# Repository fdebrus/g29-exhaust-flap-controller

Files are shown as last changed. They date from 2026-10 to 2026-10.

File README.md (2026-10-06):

# G29 Exhaust Flap Controller

Open-source controller for the exhaust flap of the **BMW Z4 G29 M40i**: open the flap on demand
(even in Comfort mode) while keeping **full factory behaviour** the rest of the time.

Commercial kits exist, but the cheap ones replace the factory control entirely (their "AUTO" mode
does not hand control back to the car). This project fixes that with a fail-safe relay design.

## How it works

```
                       +------------------+
Engine computer (DME) -| NC              |
                       |   DPDT relay    COM|--- Exhaust flap actuator (signal wire)
ESP32-C3 PWM driver ---| NO              |
                       +------------------+
```

- **AUTO** (default, relay released): the car drives the flap exactly as from the factory.
- **ON / OFF**: the ESP32-C3 energizes the relay and sends its own PWM signal (flap open / closed).
- **Fail-safe**: if the board loses power, resets or crashes, the relay drops and the car is back in control.
- Only the **signal wire** is cut. The actuator's +12 V and ground stay on the original harness.
  The board takes its own power from a fused source in the trunk, not from the actuator wires.
- The relay's second pole connects a **dummy load** to the DME while the ESP32-C3 is in control,
  to try to avoid an open-circuit fault code.

Controls: the original 433 MHz key fob (ON / AUTO / OFF) and the kit's dashboard button, whose
cabin box also transmits on 433 MHz. Nothing is wired from the dashboard to the board.

## Hardware

Board **v3**: Seeed XIAO ESP32-C3 on socket strips, **on-board 433 MHz receiver** (JSMSEMI
SYN480R + 13.52127 MHz crystal, wire antenna pad), SMT passives (0603/0805, SMA, SOD-123,
SOT-23, DPAK), Omron G5V-2 DPDT relay, two 2-pin screw terminals. **58 x 40 mm**, 2 layers,
29 placed parts, designed for JLCPCB assembly (`hardware/v3-xiao-esp32c3/jlcpcb/`). No RXB6
module any more.

Earlier boards are in the git history only: v2 (same circuit with through-hole parts, an RXB6
module and a wired dashboard input, 60 x 46 mm) before the `v2-removed` tag, v1 (ESP32-DevKitC)
before the `v1-removed` tag.

## Project status

- [x] Teardown and analysis of the commercial kit ([docs/findings.md](docs/findings.md))
- [x] Firmware (AUTO / ON / OFF over 433 MHz: fob + dashboard button, fail-safe start)
- [x] PCB v3 (XIAO ESP32-C3, on-board SYN480R receiver, SMT, 58 x 40 mm, 3 mounting holes, DRC clean)
- [x] 3D-printed enclosure (OpenSCAD, 62.8 x 44.8 x 26 mm, not yet test-printed)
- [ ] Receiver sensitivity check against an RXB6 (first board)
- [x] Harness survey on the car: tap point and wire identification ([docs/harness.md](docs/harness.md))
- [ ] **Bench measurement of the kit's output signal** ([docs/measurement.md](docs/measurement.md))
- [ ] Measurement on the car (DME signal, actuator input impedance)
- [ ] Set PWM frequency / duty cycles in the firmware
- [ ] Verify XIAO footprint (1:1 print) and order the assembled PCB
- [ ] Assembly, bench test, installation ([docs/installation.md](docs/installation.md))
- [ ] Check fault memory after a few drives

## Repository layout

| Path | Content |
| --- | --- |
| `firmware/g29_exhaust_flap_xiao/` | Firmware (Seeed XIAO ESP32-C3) |
| `hardware/v3-xiao-esp32c3/` | KiCad board, Gerbers, previews, DRC report, JLCPCB BOM + CPL, 3D-printed enclosure |
| `tools/pcb-generator/` | Scripts that regenerate the board (KiCad 7 + freerouting) |
| `docs/` | Findings, harness survey, measurement, installation, shopping list |

## Important values still to confirm

The firmware PWM values are **placeholders** until measured:

| Parameter | Current value | Source |
| --- | --- | --- |
| `PWM_FREQ_HZ` | 100 | guess - **must be measured** |
| `DUTY_OPEN_PCT` | 95 % | BMW F30 measurement, not verified on G29 |
| `DUTY_CLOSED_PCT` | 5 % | BMW F30 measurement, not verified on G29 |

## Disclaimer

Personal project, provided as-is. Modifying the exhaust behaviour may affect road legality
(noise approval), the vehicle inspection, warranty and insurance. The DME may log fault codes while
the controller is in ON/OFF mode. Measure before connecting anything to the car. Use at your own risk.

## License

MIT - see [LICENSE](LICENSE).

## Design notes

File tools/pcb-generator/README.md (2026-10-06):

# PCB generator (v3)

Regenerates `hardware/v3-xiao-esp32c3` from Python, so placement changes are reproducible.

Requirements: KiCad 7 (with the `pcbnew` Python module and standard footprint libraries),
Java 21, [freerouting](https://github.com/freerouting/freerouting) 2.x.

```bash
FREEROUTING_JAR=/path/to/freerouting-2.1.0.jar ./run_all.sh
```

- `build_pcb.py` - footprints, positions, nets, board outline, edge keep-out ring (the netlist lives here)
- `run_all.sh` - design rules (0.3 mm signal / 0.6 mm power, 0.2 mm clearance), Specctra export, autorouting, finishing
- `finish_pcb.py` - imports the routes, adds ground pours and silkscreen, runs DRC

Output: `g29_flap_xiao.kicad_pcb` and `drc.rpt` in this folder. Then:

```bash
kicad-cli pcb export gerbers --layers F.Cu,B.Cu,F.Paste,B.Paste,F.SilkS,B.SilkS,F.Mask,B.Mask,Edge.Cuts -o gerbers/ --no-protel-ext g29_flap_xiao.kicad_pcb
kicad-cli pcb export drill -o gerbers/ --format excellon --excellon-separate-th g29_flap_xiao.kicad_pcb
```

DRC on the current board: 0 errors, 0 warnings (apart from KiCad's "library not configured"
notes, which come from loading footprints by path), 0 unconnected pads.

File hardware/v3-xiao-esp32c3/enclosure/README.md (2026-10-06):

# Enclosure (3D printed)

Parametric OpenSCAD model for board v3 (58 x 40 mm). Outer size **62.8 x 44.8 x 26 mm**
(base 24 mm + lid), inner height 17 mm above the PCB.

## Features
- Board held by **three M2.5 self-tapping screws** (board holes H1-H3) into bosses, plus a
  support ledge along the left edge. Board sits 4 mm above the floor.
- **USB-C opening** in the top wall for the XIAO (flash without opening the box).
- **Two wire openings** in the bottom wall for the J1 and J3 screw terminals.
- **Antenna exit** (3.2 mm) in the top wall right above the ANT pad: the 17 cm wire goes straight
  up from the pad and out. Run it along the harness, away from the relay coil.
- Snap-fit lid with lip and vent slots. Two **fixing tabs** with 4.2 mm holes for cable ties or
  screws in the trunk cavity.

## Printing
PETG or ASA (the trunk gets warm in summer; PLA softens). 0.2 mm layers, 3 perimeters,
20 % infill, no supports: both parts print flat, open side up. Boss hole 2.0 mm for PETG
(`boss_id`), 2.2 mm for harder filaments.

## Files
- `enclosure.scad` - the model; `part = "base" | "lid" | "both"`
- `enclosure_base.stl`, `enclosure_lid.stl`
- `assembly.scad` - board with approximate component bodies inside the base, for the renders
- `render_open.png`, `render_top.png`, `render_exploded.png`

## Regenerating
```bash
openscad -o enclosure_base.stl -D 'part="base"' enclosure.scad
openscad -o enclosure_lid.stl  -D 'part="lid"'  enclosure.scad
xvfb-run openscad -o render_open.png --camera=31,22,14,50,0,200,235 -D show_lid=false assembly.scad
```
All dimensions (wall, clearance, cutout positions, boss size) are parameters at the top of
`enclosure.scad`. Cutout positions are in board coordinates (origin top-left of the PCB).

Not yet test-printed: check the lid snap fit on the first print and adjust `clr` (0.4 mm) if
the board is tight in the cavity.

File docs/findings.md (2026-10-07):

# Findings

Everything we know so far, with how confident we are. "Verified" means seen or measured directly;
"inferred" means deduced, still to be confirmed.

## The car

| Item | Status | Notes |
|---|---|---|
| Z4 G29 M40i has an electrically controlled exhaust flap | Verified | |
| Actuator part number 18308686640, 3-pin connector, driven by the DME | From parts listings | Shared with G20 M340i, G42, G05 X5, F90 M5 and others |
| Signal type is PWM | **Inferred** | See evidence below |
| PWM 5 % = closed, 95 % = open | **Inferred** | Measured on an F30 330i (different actuator), posted on the Pico Technology forum |
| Disconnecting the actuator logs DME fault 138104 (exhaust flap activation, open circuit) | From fault-code listings | Not tested on our car |
| Some commercial modules claim no fault codes | Vendor claim (dAHLer) | Suggests the DME can be kept happy with a load |

## The commercial kit (Chinese, "宝马原厂电机控制器")

The kit has three parts: a replacement light-switch panel with an exhaust button, a cabin box,
a trunk box, and a 3-button key fob (ON / AUTO / OFF). Seller confirmed in writing that it
**replaces** the factory cable: its AUTO button does **not** give control back to the car.

### Key fob
- Resonator marked **R433** -> transmits on **433.92 MHz** (EU-permitted band).

### Cabin box (connected to the dashboard button)
- Blue carrier board with **two plug-in RF modules**, each with its own antenna and an unmarked 8-pin chip.
- Crystals **9.81563 MHz** and **13.52127 MHz**. These match the SYN5xx receiver family values for
  **315 MHz** and **433.92 MHz** respectively.
- Central microcontroller, markings removed.
- Seller's answer "433-315" confirms the two bands.
- Note: 315 MHz is not a permitted short-range band in the EU.

### Trunk box ("HJS-3线电机驱动板-A-V1.1-211118" = "HJS 3-wire motor driver board, A, V1.1, 2021-11-18")
- **U3 marked "531R"** -> likely **SYN531R** ASK receiver; crystal **13.52127 MHz** -> receives on **433.92 MHz**.
- **U1**: 28-pin microcontroller, markings removed. Unpopulated headers P1/P2/P3 (programming/debug).
- **U2**: 78L05 regulator. **D1/D4/D5**: SS14 Schottky. **R1 ("α 075")**: probably a 0.75 A resettable fuse.
- **Output stage**: two identical channels, small NPN transistors (marked "1AM", typically MMBT3904)
  with 510 Ω resistors (R6, R7) and 2 k / 4.7 k resistors. **No LIN transceiver** on the board.
- Two channels probably serve cars with two flap actuators.
- Seller: signal voltage 12 V, signal wire in their harness is **red-black**.

### Bench measurement of the trunk box (7 Oct 2026)
Stabilised 12.0 V supply, multimeter (DC) on the three output wires: black = ground, red = 12 V
permanent, yellow = signal.

| Kit mode | Yellow (V) | As % of supply |
| --- | --- | --- |
| Open | 10.48 | 87 % |
| Auto | 5.95 | 50 % |
| Off | 1.41 | 12 % |

These are multimeter averages: three fixed levels, consistent with a PWM at 12 V level driven
actively (push-pull), or with three DC levels; a multimeter cannot tell. Frequency and duty cycle
are to be measured with `tools/pwm_probe` (see [measurement.md](measurement.md)).

**The kit never connects to the DME.** Its harness drives the actuator only; the car's signal wire
is left unconnected. "Auto" is simply a fixed 50 % output, not a copy of the car's signal. This is
the real reason the kit cannot hand control back: there is no path for it.

### Conclusion on signal type
Three fixed output levels at 12 V, a transistor output stage, a 3-wire actuator and the F30 data
all point to **PWM at 12 V level, driven actively**. Consequence for our board: fit **R9** (1 k
pull-up) so the open-collector driver produces a 12 V level too. Frequency still to be measured.

### What the internet says about the DME signal (Oct 2026)
Collected from forum threads where people reverse-engineered three-wire BMW/VAG flap actuators.
None of it is for the G29 specifically; weight accordingly.

| Claim | Source | Weight |
| ----- | --- | --- |
| PWM ≈ **100 Hz** from the ECU to the actuator | mikrocontroller.net 499517 and 310954, forum-3dcenter.org 587113 (actuator-maker insider), Pico forum (F30) | Four independent sources agree: strong |
| Duty 10 % / 90 % (or 5 % / 95 %) for the two end positions, control is stepless | mikrocontroller.net 310954, Pico forum | Consistent with our kit (12 % / 87 %); the SST controller offers ¼ ½ ¾ positions, so proportional: strong |
| Polarity: high = open | Pico F30 capture, our kit | mikrocontroller.net 499517 says the opposite (9 ms *low* = open) but is second-hand: **unsettled, measure on the car** |
| Low level ≈ 2 V, high ≈ 12 V; drive the input through ~1 kΩ from 12 V | mikrocontroller.net 310954 | Matches an open-collector drive with pull-up: supports fitting R9 |
| **The actuator answers**: "smart" actuator with its own MCU; data to the ECU by ground-keying during the low phase of the ECU's PWM; two diagnostic states reported | forum-3dcenter.org 587113, mikrocontroller.net 310954 | Plausible and consistent with faults 138102/138104 being about a missing/wrong reply |

Consequence of the last point for this project: a resistor (R10/R11) cannot answer the DME, so a
fault will probably be logged while the ESP32 drives the flap. If that turns out to matter, the
fix is firmware: in ON/OFF mode, listen to the DME side (available at the relay's second pole) and
reproduce the actuator's reply. That needs the reply captured on the car with a logic analyser first.
In AUTO the DME and actuator keep a real wire between them, so the link is untouched.

### Open questions (car only)
- The DME's own frequency, levels, polarity and Comfort/Sport duty cycles (pwm_probe at the actuator connector).
- The actuator's reply in the low phase: capture a few seconds of raw waveform with the logic
  analyser (8 MHz is plenty) in Comfort and Sport.
- Whether the DME logs a fault with its signal wire open (the kit was never installed in the car,
  so there is no field evidence either way); decides whether R10/R11 or the reply emulation are needed.
- Whether the actuator is proportional (what does the flap do at the kit's 50 %?).

## Commercial alternatives (if you don't want to build)

Two plug-and-play modules list the G29 and advertise keeping the factory mode:
- **MODE Auto Concepts** valve control module (auto mode reverts to OEM control, open in any drive mode).
- **Grail Automotive** exhaust valve controller (two settings: fully open, or OEM operation).

Neither states whether the DME stays fault-free. Both are vendor claims, not independently tested.

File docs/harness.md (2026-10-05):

# Harness survey on the car (G29 M40i)

Where the actuator wiring runs, where to tap it, and how the wires were identified.
Observed on one car (2022 build). Items marked **to verify** are not yet confirmed.

## Actuator and connector

- One electric actuator on the **right-hand rear silencer**, BMW part 18308686640, 3-pin connector.
- The connector is reachable by hand from under the car, right side, without removing anything.
- The actuator pigtail runs forward under a heat-shield sleeve toward the body. No intermediate
  connector was found before the body entry, so the pigtail's wire colours cannot be followed
  visually past the sleeve.

## Where the wiring enters the body

- Right-hand side of the trunk, behind the side trim, next to the **rear power distribution box**
  (fuse box, BMW 6114 8734162).
- Remove the fuse-box cover, then lift out the black EPP foam block (press-fit, no fasteners).
- At the bottom of the cavity, below the fuse box, a large rubber **floor grommet** passes the
  rear harness to the underbody. This is the only harness exit in that area and the actuator
  wires are in it.
- The fuse box does **not** need to be removed. Do not try: it is a coded module, permanently
  fed from the battery via the thick red cable on the left of the cavity.

## Wire identification (no wiring diagram needed)

Battery negative disconnected, actuator connector unplugged.

1. Open the harness fabric tape over 15-20 cm above the grommet and fan the wires out.
2. Tone generator (Klein VDV500-705 used) on one harness-side pin of the actuator connector,
   black clip on bare chassis. Probe the fanned wires in the trunk, lowest sensitivity first.
3. Repeat for the other pins.

Result: **two** of the three pins tone normally. The **third goes silent**: it is the actuator
ground, bonded to the chassis, so the toner is shorted. This is expected and useful: the two
toning wires are supply and signal, which is all that matters.

4. Confirm each located wire with a multimeter in continuity mode between the pin and the wire
   (long test lead, fine needle through the insulation). Seal the pin-pricks with heat-shrink.
5. Battery reconnected, ignition on: back-probe the two located wires. Steady ~12 V = supply.
   Intermediate / changing between Comfort and Sport = **signal**. That is the wire to cut.

Only the signal wire is cut. The ground wire is left alone and not identified in the loom.

## Cautions in the opened loom

- The main loom above the grommet carries twisted pairs (bus lines). Do not pierce them and keep
  tap leads away from them.
- Re-wrap with harness fabric tape (tesa 51608 or 51036, 15 mm is the right width here;
  9/15/19/25/32 mm exist).

## Commercial kit Y-harness colours

The vendor's 3-pin Y-harness uses red, black and yellow. Yellow = signal is a plausible
convention, **not verified**: check the cavity number of the yellow wire against the OEM
connector, then the voltage test above.

## Related, to verify

- Owners report fuse **203** (7.5 A, the only 7.5 A in the rear box) as the flap actuator supply
  on the G29. Documented for the X3 G01, two forum reports for the G29, not confirmed here.
- Unplugging the actuator is reported to log DME fault **138104** (open circuit) on the M340i;
  not tested on the G29.

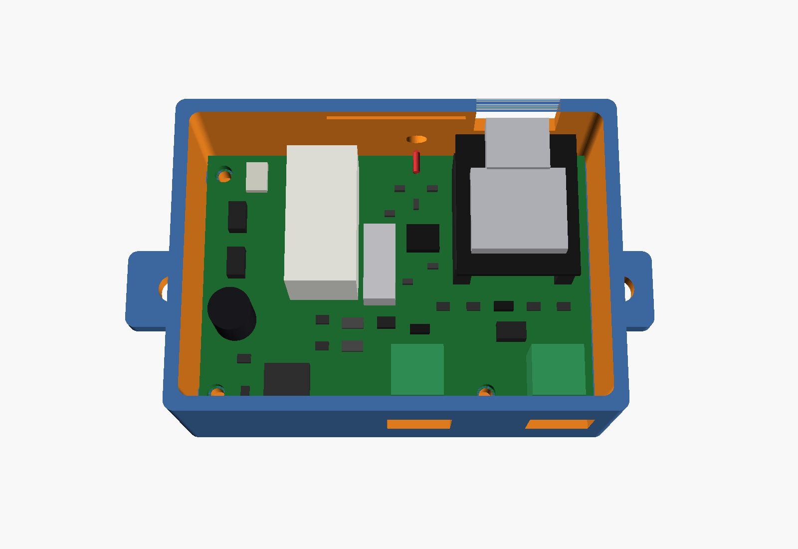
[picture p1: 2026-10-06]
hardware/v3-xiao-esp32c3/enclosure/render_top.png

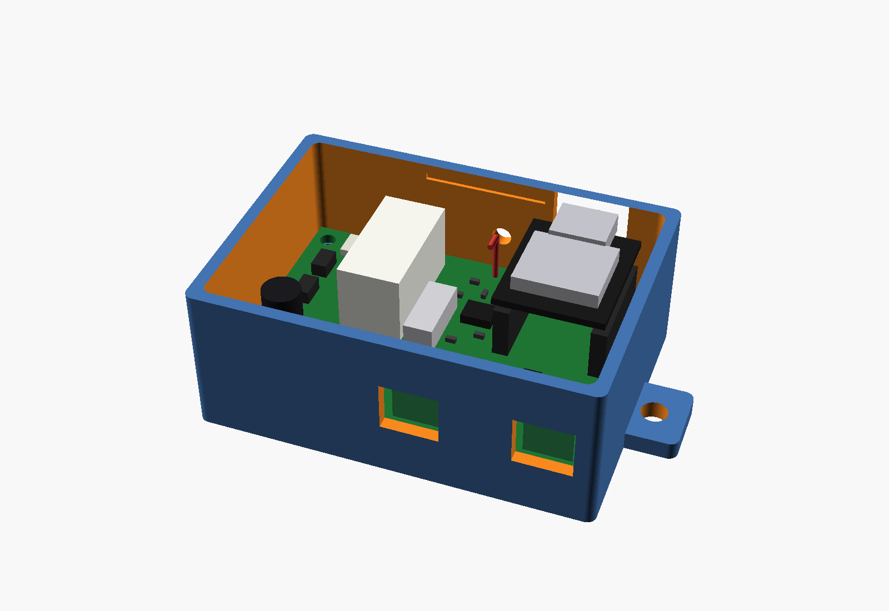
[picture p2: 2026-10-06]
hardware/v3-xiao-esp32c3/enclosure/render_open.png

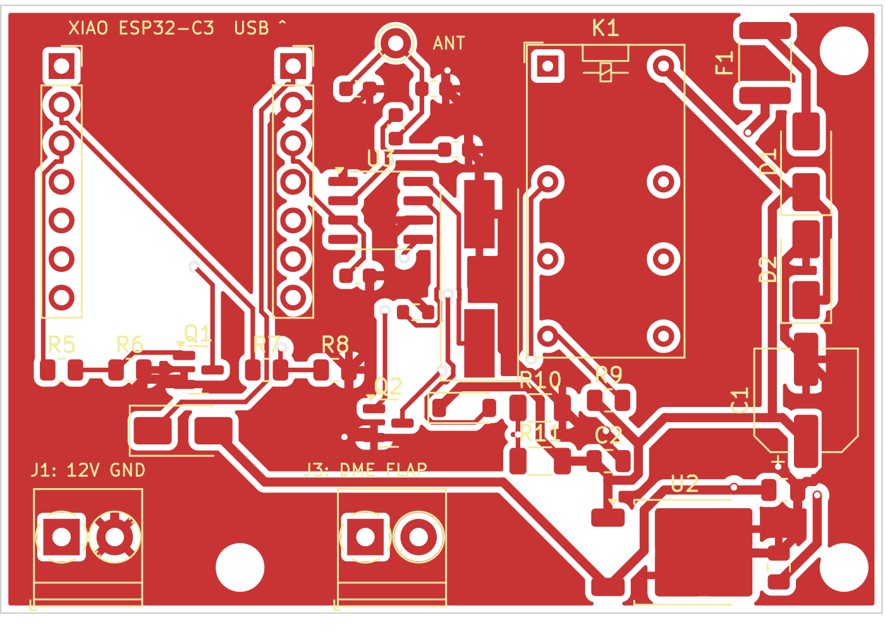
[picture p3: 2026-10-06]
hardware/v3-xiao-esp32c3/jlcpcb/preview_front.png

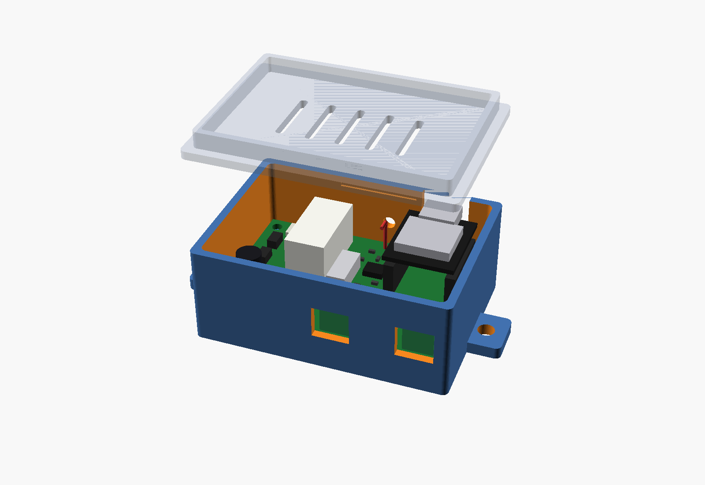
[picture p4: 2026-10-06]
hardware/v3-xiao-esp32c3/enclosure/render_exploded.png

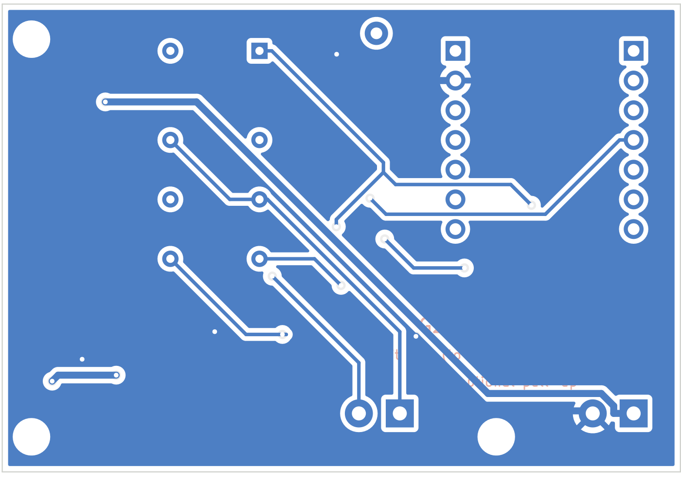
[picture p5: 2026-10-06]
hardware/v3-xiao-esp32c3/jlcpcb/preview_back.png

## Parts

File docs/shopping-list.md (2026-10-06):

# Shopping list

Full component list: `hardware/v3-xiao-esp32c3/jlcpcb/bom.csv`.

## Modules (not assembled by the PCB maker)
- **Seeed Studio XIAO ESP32-C3** (exactly this model; not S3/C6/RP2040, not the "ESP32-C3 Super Mini").
  Check the external antenna is included. Solder two 1x7 male headers if not pre-soldered.
- 17 cm of stiff insulated wire for the antenna (the 433 MHz receiver is on the board)

## Measurement
- USB logic analyser 24 MHz 8-channel (fx2lafw / PulseView compatible)
- 10 kΩ + 3.3 kΩ resistors for the input divider
- Back-probe pins, multimeter
- Tone generator + probe (Klein VDV500-705 or similar) for finding the signal wire in the trunk loom

## Installation
- Add-a-fuse tap for the rear fuse box (mini low-profile type, check yours) + 2-3 A fuse
- Automotive wire 0.5-0.75 mm², several colours
- Solder sleeves or heat-shrink butt connectors
- Enclosure: print `hardware/v3-xiao-esp32c3/enclosure/` (PETG/ASA) + 3 M2.5 x 6 self-tapping screws, cable ties
- Fabric harness tape (tesa 51608, 15 mm)

## PCB
- Gerbers in `hardware/v3-xiao-esp32c3/`, ordered with assembly from JLCPCB (see `jlcpcb/HOW_TO_UPLOAD.md`)
- If assembling yourself: 0805 passives, SMA/SOD-123 diodes, SOT-23 transistors and a DPAK
  regulator are hand-solderable with a fine tip; the relay, terminals and sockets are through-hole.

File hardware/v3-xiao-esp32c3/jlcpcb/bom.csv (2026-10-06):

Comment | Designator | Footprint | LCSC Part # | Notes
100uF 35V SMD elec 6.3x7.7 | C1 | CP_Elec_6.3x7.7 | C970686 | RVT1V101M0607 (verified in JLC library; alt C2836442)
100nF 50V 0805 | C2,C3 | C_0805_2012Metric | C49678 | CC0805KRX7R9BB104, Basic
10uF 25V 0805 | C4 | C_0805_2012Metric | C15850 | CL21A106KAYNNNE, Basic
SS14 | D1,D6 | D_SMA | C2480 | verified
SMAJ20A | D2 | D_SMA | C41376408 | SMAJ20A unidirectional
1N4148W | D5 | D_SOD-123 | C81598 | verified
PTC 0.5A 72V 1812 | F1 | Fuse_1812_4532Metric | C49318438 | 1812L050/72V (verified in JLC library)
Screw terminal 2P 3.5mm | J1,J3 | TerminalBlock_Phoenix_PT-1,5-2-3.5-H_1x02_P3.50mm_Horizontal | C474892 | KF350-3.5-2P (in stock Oct 2026)
G5V-2-H1 DC12 | K1 | Relay_DPDT_Omron_G5V-2 | C128021 | verified; Extended
S8050 SOT-23 | Q1,Q2 | SOT-23 | C50229533 | S8050 SOT-23; 1 B, 2 E, 3 C
1k 0805 | R5,R7 | R_0805_2012Metric | C17513 | 0805W8F1001T5E, Basic
100k 0805 | R6,R8 | R_0805_2012Metric | C149504 | 0805W8F1003T5E, Basic
Female header 1x7 2.54 | U1A,U1B | PinSocket_1x07_P2.54mm_Vertical | C7509513 | DS1023-1x7SF11
78M05 TO-252 | U2 | TO-252-2 | C9070 | CJ78M05 (verified in JLC library); pin 1 IN, tab GND, pin 3 OUT
SYN480R (JSMSEMI) | U3 | SOIC-8_3.9x4.9mm_P1.27mm | C916347 | JSMSEMI SYN480R SOIC-8 only; Synoxo part has a different pinout
13.52127MHz 20pF | Y1 | Crystal_SMD_HC49-SD | C279599 | ECEC C13521J007 HC-49S-SMD (verified in JLC library)
1.8pF C0G 0603 | C7 | C_0603_1608Metric | C1640 | 0603CG1R8C500NT C0G 50V
6.8pF C0G 0603 | C8 | C_0603_1608Metric | C1679 | 0603CG6R8C500NT C0G 50V
1uF 0603 | C9 | C_0603_1608Metric | C15849 | CL10A105KB8NNNC
27nH 0603 | L1 | L_0603_1608Metric | C316380 | Sunlord SDWL1608C27NJSTF wire-wound Q38
47nH 0603 | L2 | L_0603_1608Metric | C60035 | Sunlord SDWL1608C47NJSTF wire-wound, Q36
0R 0603 | R12 | R_0603_1608Metric | C21189 | 0603WAF0000T5E Basic

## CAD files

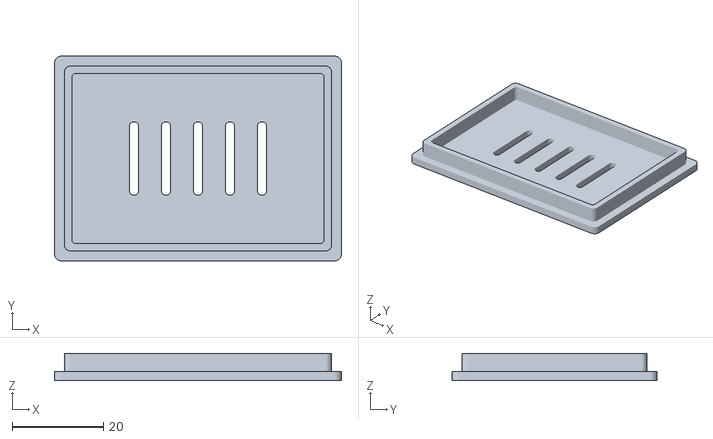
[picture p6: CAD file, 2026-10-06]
hardware/v3-xiao-esp32c3/enclosure/enclosure_lid.stl
62.8 x 44.8 x 6.00

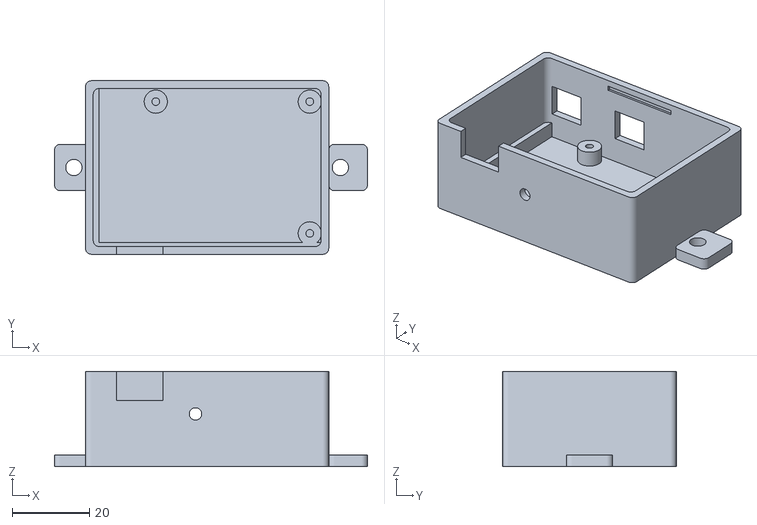
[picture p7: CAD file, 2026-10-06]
hardware/v3-xiao-esp32c3/enclosure/enclosure_base.stl
80.8 x 44.8 x 24.6

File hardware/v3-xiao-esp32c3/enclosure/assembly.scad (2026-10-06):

// Assembly view: board v3 with its main components inside the enclosure.
// For visualisation only (component bodies are approximate boxes).
include <enclosure.scad>
part = "none";                 // suppress the enclosure's own output
show_lid = false;              // true: lid in place (translucent); false: lid off
exploded = 0;                  // mm to lift the lid

z0 = pcb_z;                    // PCB underside
module at(x, y, z = 0) translate([bx(x), by(y), z0 + pcb_t + z]) children();

module pcb() {
  translate([bx(0), by(0), z0]) color([0.12, 0.45, 0.2]) difference() {
    cube([pcb_x, pcb_y, pcb_t]);
    for (h = holes) translate([h[0], h[1], -1]) cylinder(d = 2.7, h = 5);
  }
}
module socket(x, y, n) at(x - 1.27, y - 1.27) color([0.15, 0.15, 0.15]) cube([2.54, 2.54 * n, 8.5]);
module xiao() {   // 21 x 17.5, sits on the two 1x7 sockets, USB at the top edge
  at(11.62 - 8.75, 11.62 - 10.5, 8.5 + 2.5) {
    color([0.1, 0.1, 0.1]) cube([17.5, 21, 1.2]);
    translate([17.5/2 - 4.5, -1.3, 1.2]) color([0.75, 0.75, 0.78]) cube([9, 7.5, 3.2]);     // USB-C
    translate([2, 6, 1.2]) color([0.75, 0.75, 0.78]) cube([13.5, 12, 2.4]);                  // shield can
  }
}
module receiver() {
  smd(25, 13.5, 5, 4, 1.6, [0.1, 0.1, 0.1]);                                                 // U3 SYN480R
  at(31.5 - 2.35, 18 - 5.75, 0) color([0.8, 0.8, 0.82]) cube([4.7, 11.5, 4.2]);              // Y1 HC-49S-SMD
  at(26, 2.5, 0) color([0.8, 0.2, 0.2]) { cylinder(d = 1, h = 8); translate([0, 0, 8]) rotate([-90, 0, 0]) cylinder(d = 1, h = 3); }   // antenna wire to the exit hole
}
module relay() at(36 - 1.3, 4 - 1.4, 0) color([0.95, 0.95, 0.92]) cube([10.2, 20.3, 11.5]);
module smd(x, y, l, w, h, c = [0.25, 0.25, 0.25], rot = 0) at(x, y) rotate([0, 0, rot]) translate([-l/2, -w/2, 0]) color(c) cube([l, w, h]);
module board_parts() {
  socket(4, 4, 7); socket(19.24, 4, 7);
  xiao(); receiver(); relay();
  at(53, 26) color([0.1, 0.1, 0.12]) cylinder(d = 6.3, h = 7.7);                             // C1
  smd(45, 36, 6.6, 6.1, 2.3, [0.2, 0.2, 0.2]);                                               // U2 body
  smd(50.3, 3.8, 4.5, 3.2, 1.2, [0.85, 0.85, 0.8], 90);                                      // F1
  smd(53, 10.3, 4.3, 2.6, 2.3, [0.15, 0.15, 0.15], 90); smd(53, 17.4, 4.3, 2.6, 2.3, [0.15, 0.15, 0.15], 90);
  smd(12, 28, 4.3, 2.6, 2.3, [0.15, 0.15, 0.15], 0);                                         // D1 D2 D6
  for (p = [[4, 24], [8.5, 24], [17.5, 24], [22, 24], [40, 26], [40, 30], [51.5, 31.9]]) smd(p[0], p[1], 2, 1.25, 0.6, [0.2, 0.2, 0.2], 0);
  smd(51.2, 37, 2, 1.25, 0.6, [0.2, 0.2, 0.2], 90);
  for (p = [[23.5, 5.5], [28.5, 5.5], [30, 9.5], [23.5, 17.8], [27.3, 20.2]]) smd(p[0], p[1], 1.6, 0.8, 0.8, [0.25, 0.25, 0.25], 0);
  smd(26, 8, 1.6, 0.8, 0.8, [0.25, 0.25, 0.25], 90);                                         // RF 0603s
  smd(13, 24, 2.9, 1.3, 1.1, [0.1, 0.1, 0.1]); smd(25.5, 27.5, 2.9, 1.3, 1.1, [0.1, 0.1, 0.1]);   // Q1 Q2
  smd(30.5, 26.5, 2.7, 1.6, 1.1, [0.15, 0.15, 0.15]);                                        // D5
  for (p = [[35.5, 26.5], [35.5, 30]]) smd(p[0], p[1], 3.2, 1.6, 0.6, [0.3, 0.3, 0.3]);     // R10 R11 (DNP)
  for (x = [4, 24]) at(x - 1.75, 35 - 3.6) color([0.2, 0.6, 0.35]) cube([7.5, 7.3, 8.3]);    // J1 J3
}

base();
pcb(); board_parts();
if (show_lid) translate([0, 0, base_h + exploded]) color([0.6, 0.65, 0.75, 0.35]) lid();

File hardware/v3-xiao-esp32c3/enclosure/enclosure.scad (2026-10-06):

// G29 exhaust flap controller - enclosure for board v3 (58 x 40 mm)
// Two-part box: base with three M2.5 screw bosses (board holes H1-H3) and a support ledge,
// lid with snap lip. The 433 MHz receiver is on the board (SYN480R), so one low variant only.
// Print: PETG or ASA (trunk gets warm), 0.2 mm layers, 3 perimeters, no supports.

// ---------- PCB ----------
pcb_x = 58;  pcb_y = 40;  pcb_t = 1.6;
clr   = 0.4;              // play around the PCB in the rails
// ---------- walls ----------
wall  = 2.0;  floor_t = 2.0;  lid_t = 2.0;
rail_h = 4.0;             // PCB underside above the floor (room for solder joints and the relay pins)
rail_d = 1.5;             // support ledge depth along the left wall
boss_od = 6.0; boss_id = 2.0;   // M2.5 self-tapping into PETG; use 2.2 for ASA/PLA
holes = [[55.5, 3.0], [15.75, 37.0], [55.5, 37.0]];   // H1 H2 H3, board coordinates
// ---------- heights above PCB top ----------
h_inner = 17;             // XIAO on sockets ~14 mm, relay 11.5 mm
// ---------- cutouts (board coordinates, origin = PCB top-left, x right, y down) ----------
usb_cx = 11.6;  usb_w = 12;  usb_z0 = 9.5;  usb_z1 = 17;     // XIAO USB-C, top wall (y = 0)
j1_x0 = 1.7;  j1_x1 = 9.8;                                   // J1 wire entry, bottom wall (y = pcb_y)
j3_x0 = 21.7; j3_x1 = 29.8;                                  // J3 wire entry
term_z0 = 1.0; term_z1 = 9.0;                                // terminal opening height above PCB top
ant_x = 26.0;  ant_hole = 3.2;  ant_z = 6;                   // antenna exit, top wall above the ANT pad (0 = none)
// ---------- fixing tabs ----------
tab_w = 12; tab_l = 8; tab_hole = 4.2;

$fn = 48;
ix = pcb_x + 2*clr;        // inner cavity x (between rails)
iy = pcb_y + 2*clr;        // inner cavity y
ox = ix + 2*wall;  oy = iy + 2*wall;
base_h = floor_t + rail_h + pcb_t + h_inner;   // outer height of the base (lid sits on top)
lip_h = 4;

module rbox(x, y, z, r = 1.5) {
  hull() for (sx = [r, x - r], sy = [r, y - r]) translate([sx, sy, 0]) cylinder(r = r, h = z);
}

// board coordinate -> base coordinate
function bx(x) = wall + clr + x;
function by(y) = wall + clr + y;
pcb_z = floor_t + rail_h;   // z of PCB underside

module base() {
  difference() {
    union() {
      rbox(ox, oy, base_h);
      // fixing tabs on the short sides
      for (sx = [-tab_l, ox]) translate([sx, oy/2 - tab_w/2, 0]) rbox(tab_l + 2, tab_w, floor_t + 1);
    }
    // cavity above the floor (full width between walls, rails are added back below)
    translate([wall, wall, floor_t]) rbox(ix, iy, base_h);
    // tab holes
    for (sx = [-tab_l/2 + 1, ox + tab_l/2 - 1]) translate([sx, oy/2, -1]) cylinder(d = tab_hole, h = floor_t + 3);
    // USB-C cutout, top wall (y = 0 side)
    translate([bx(usb_cx) - usb_w/2, -1, pcb_z + pcb_t + usb_z0]) cube([usb_w, wall + clr + 2, usb_z1 - usb_z0]);
    // terminal openings, bottom wall (y = pcb_y side)
    for (xr = [[j1_x0, j1_x1], [j3_x0, j3_x1]])
      translate([bx(xr[0]) - 0.5, oy - wall - 1, pcb_z + pcb_t + term_z0]) cube([xr[1] - xr[0] + 1, wall + 2, term_z1 - term_z0]);
    // antenna exit, top wall (y = 0), above the ANT pad
    if (ant_hole > 0) translate([bx(ant_x), -1, pcb_z + pcb_t + ant_z]) rotate([-90, 0, 0]) cylinder(d = ant_hole, h = wall + clr + 2);
    // lid snap grooves inside the long walls
    for (sy = [wall - 0.6, oy - wall - 0.6]) translate([ox/2 - 10, sy, base_h - lip_h + 1.2]) cube([20, 1.2, 1.2]);
  }
  // screw bosses under the board holes
  for (h = holes) translate([bx(h[0]), by(h[1]), floor_t - 0.01]) difference() {
    cylinder(d = boss_od, h = rail_h + 0.01);
    translate([0, 0, 0.8]) cylinder(d = boss_id, h = rail_h);
  }
  // support ledge along the left wall (no boss on that side)
  translate([wall, wall, floor_t]) cube([rail_d, iy, rail_h]);
  // stop ledge at the top wall
  translate([wall, wall, floor_t]) cube([ix, 1.0, rail_h]);
}

module lid() {
  difference() {
    union() {
      rbox(ox, oy, lid_t);
      translate([wall + 0.2, wall + 0.2, lid_t]) difference() {      // lip
        rbox(ix - 0.4, iy - 0.4, lip_h, 1.2);
        translate([1.6, 1.6, -1]) rbox(ix - 3.6, iy - 3.6, lip_h + 2, 0.8);
      }
    }
    // vent slots
    for (i = [0:4]) translate([ox/2 - 15 + i*7, oy/2 - 8, -1]) rbox(2, 16, lid_t + 2, 0.9);
  }
  // snap nubs on the lip (engage the wall grooves)
  for (sy = [wall + 0.2, oy - wall - 1.0]) translate([ox/2 - 10, sy, lid_t + lip_h - 1.6]) cube([20, 0.8, 1.0]);
}

// ---------- what to render ----------
part = "both";   // "base", "lid", "both" or "none"
if (part == "base" || part == "both") base();
if (part == "lid")  lid();
if (part == "both") translate([0, oy + 10, 0]) lid();

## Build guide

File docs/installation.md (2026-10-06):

# Assembly and installation

## Before ordering the PCB

1. Measurement done, signal confirmed **PWM** ([measurement.md](measurement.md)).
2. Print `hardware/v3-xiao-esp32c3/preview_front.png` at 1:1 (58 x 40 mm) and lay the XIAO on it:
   rows 15.24 mm apart; USB at top; left column D0..D6, right column 5V, GND, 3V3, D10, D9, D8, D7.
3. Order from JLCPCB with assembly: `hardware/v3-xiao-esp32c3/jlcpcb/HOW_TO_UPLOAD.md`.

## Assembly notes

- JLCPCB places everything except the XIAO and the DNP parts (R9, R10, R11).
- If hand-soldering the SMD parts: 0805 passives and SMA/SOD-123/SOT-23 first, then the DPAK
  regulator, then the through-hole relay, terminals and socket strips.
- Diode cathode = pad 1 = the end with the silkscreen bar: D1 and D6 (SS14) bar toward +12 V /
  toward the XIAO; D2 (TVS) bar toward +12 V; D5 (1N4148W) bar toward +12 V.
- Q1/Q2 S8050 SOT-23: pin 1 base, pin 2 emitter, pin 3 collector (the lone pad).
- **Antenna**: solder a **17 cm** straight wire (quarter wave at 433.92 MHz) into the ANT pad at the
  top edge, route it out through the enclosure hole and along the harness, away from the relay coil.
- **Receiver**: U3 must be the JSMSEMI SYN480R (C916347). The Synoxo SYN480R has a different pinout
  and needs a 6.7458 MHz crystal; it does not work on this board. R12 (0R) disables the squelch;
  leave it out if the data line is too noisy in AUTO mode (costs 3 dB sensitivity).
- Fit **R9** (1k pull-up, 0805) and **R10 or R11** (1206 dummy load) only with the measured values.

## Firmware

1. Arduino IDE, ESP32 core 2.x or 3.x, board **XIAO_ESP32C3**, enable "USB CDC On Boot".
2. Library: **rc-switch** (Library Manager).
3. Set `PWM_FREQ_HZ`, `DUTY_OPEN_PCT`, `DUTY_CLOSED_PCT` from the measurements.
4. Flash with the RF codes at 0, open the Serial Monitor (115200), press ON / AUTO / OFF on the fob
   and then the dashboard button (its cabin box also transmits on 433 MHz). Copy the codes into
   `RF_CODE_ON`, `RF_CODE_AUTO`, `RF_CODE_OFF` and, if they differ from the fob, `RF_CODE_BTN_ON`,
   `RF_CODE_BTN_OFF`. Flash again.

Pins: GPIO3 PWM, GPIO4 relay, GPIO5 receiver data (U3 DO). No wired inputs.

## Bench test (before the car)

- 12 V supply on J1. Board starts in AUTO: relay off.
- Fob ON -> relay clicks, PWM on J3 "FLAP" when relay is on.
- Fob AUTO -> relay off. Fob OFF -> forced closed, back to AUTO after 15 minutes.
- Check the signal on the FLAP terminal with the logic analyser (with divider): same frequency/duty as measured.
- Remove power while in ON -> relay must drop.

## Where to work on the car

Right-hand side of the trunk, behind the fuse-box cover and the EPP foam block. The actuator
wiring passes through the floor grommet below the rear power distribution box. Full survey and
wire identification procedure: [harness.md](harness.md).

Battery negative disconnected before opening the loom or cutting anything.

## Connections in the car

| Terminal | Pin  | Connect to |
| --- | ---- | --- |
| J1 PWR | 12V  | Switched +12 V (after ignition) via an add-a-fuse tap in the rear fuse box, own 2-3 A fuse. **Not** the actuator supply wire. |
| J1 PWR | GND  | Chassis bolt or battery negative post. **Not** the actuator ground wire. |
| J3 FLAP  | DME  | Signal wire, **car side** (cut wire, end going to the DME) |
| J3 FLAP  | FLAP | Signal wire, **actuator side** |

There is no connector for the dashboard button: the kit's cabin box sends the button presses over
433 MHz and the on-board receiver picks them up like the fob.

- Only the **signal wire** is cut, in the trunk loom above the grommet. Actuator +12 V and ground
  stay untouched; the ground wire does not even need to be located.
- Use solder sleeves or crimped, heat-shrunk butt connectors. No scotch-lock taps.
- Keep the original connector intact so the car can be returned to stock.
- Keep tap leads away from the twisted pairs in the loom. Finish with fabric harness tape.
- Mount the box in the trunk cavity away from the fuse box and the battery positive cable.
  A 3D-printed enclosure is in `hardware/v3-xiao-esp32c3/enclosure/` (M2.5 screws into bosses,
  USB-C and terminal openings, fixing tabs for cable ties).

## After installation

- Drive in AUTO: the flap must behave exactly as before (Comfort / Sport).
- Read the fault memory (e.g. BimmerLink / BimmerCode with a compatible adapter) after a few drives,
  in AUTO and after using ON/OFF. Note any code (expected candidate: 138104).

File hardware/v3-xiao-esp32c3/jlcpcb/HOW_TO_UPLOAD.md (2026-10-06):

# JLCPCB upload set (board v3, on-board SYN480R receiver)

Files: `../g29_flap_v3_gerbers.zip`, `bom.csv`, `positions.csv`.

Order: 2 layers, 1.6 mm, 5 pcs, default options. PCB Assembly → **Standard** (the relay,
terminals and socket strips are through-hole), assemble 2 boards, top side only.

## Parts matching

Every BOM line carries the LCSC number that was matched and verified in stock in October 2026.
If one has gone out of stock, pick an equivalent in the same package; the two that must not be
substituted blindly are **U3** (JSMSEMI SYN480R C916347 only; the Synoxo SYN480R has another
pinout and crystal) and **Y1** (13.52127 MHz, 20 pF load).

Not in the files (DNP or hand-soldered): R9, R10, R11, the XIAO ESP32-C3, the antenna wire (ANT1 pad).

## Placement preview

Validated on the first upload of this board; nothing needed rotating. For reference:
K1 pin-1 mark at the top square pad (CPL gives body centre, rotation 270). Diodes: pad 1 = cathode =
silkscreen bar; JLC's "A"/"+" mark on the other pad (D1, D2: top; D5, D6: right). C1 "+" at the
bottom. Q1/Q2, U2, U3: pin-1 dot on the top-left pad. Terminals: wire openings toward the bottom edge.

Check the DFM report a few hours after ordering before production starts.

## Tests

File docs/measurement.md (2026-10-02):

# Measurement procedure

Goal: confirm PWM, and get the **frequency** and **duty cycles** for the firmware, plus the
dummy-load and pull-up values for the PCB.

## What PWM means

The signal wire switches between 0 V and 12 V at a fixed rhythm (the **frequency**, in Hz).
The share of each cycle spent at 12 V is the **duty cycle** (%). The actuator reads the duty
cycle as a position: e.g. 5 % closed, 95 % open, values in between = intermediate positions.

## Equipment

- USB logic analyser, 24 MHz 8-channel (fx2lafw-compatible clone, ~10 EUR)
- [PulseView](https://sigrok.org/wiki/PulseView) (free). On Windows, install the driver with Zadig as described on the sigrok wiki.
- 10 kΩ and 3.3 kΩ resistors (voltage divider)
- Multimeter, back-probe pins
- Laptop running on battery

## Protect the analyser - always

The analyser inputs accept **5 V maximum**. Car signals are 12-14 V.

```
 signal wire ---[ 10 kΩ ]---+--- CH1
                            |
                         [ 3.3 kΩ ]
                            |
 ground ------------------- +--- GND (analyser)
```

14 V in -> about 3.5 V on CH1. Always connect the analyser GND to the circuit ground.

## Step 1 - Bench test on the commercial kit (no car needed)

1. Power the kit's **trunk box** with 12 V (bench supply or 12 V battery).
2. Divider input on the **red-black** output wire (seller's information), analyser GND on the box ground.
3. PulseView: driver `fx2lafw`, sample rate >= 1 MHz, a few seconds of capture.
4. Press **ON** on the fob, capture. Press **OFF**, capture.

Read:
- Regular square wave, duty cycle changes ON vs OFF -> **PWM**. Note frequency and both duty cycles.
- Irregular bursts that don't change shape -> possibly **LIN** (PulseView has a LIN decoder). Stop and redesign.

Note: this shows what the kit sends. The car may use other values - step 2 checks that.

## Step 2 - On the car (DME signal)

1. Back-probe the actuator connector signal wire, connector **plugged in**, ignition on.
2. Capture in **Comfort**, then **Sport**, engine running.
3. Note frequency and duty cycle in each mode.

Use the DME values for the firmware if they differ from the kit.

## Step 3 - Actuator input (for R9 / R10 / R11)

Connector **unplugged**, multimeter on the **actuator side**:
- Resistance signal pin -> ground, and signal pin -> +12 V pin.
- This sizes the dummy load (fit R10 to GND **or** R11 to +12 V, same value as measured).
- If the line floats with the actuator alone, the DME output is probably open-collector and **R9** (pull-up) is needed.

## Results (fill in)

| | Kit ON | Kit OFF | Car Comfort | Car Sport |
|---|---|---|---|---|
| Frequency (Hz) | | | | |
| Duty cycle (%) | | | | |

| Actuator measurement | Value |
|---|---|
| Signal -> GND | |
| Signal -> +12 V | |

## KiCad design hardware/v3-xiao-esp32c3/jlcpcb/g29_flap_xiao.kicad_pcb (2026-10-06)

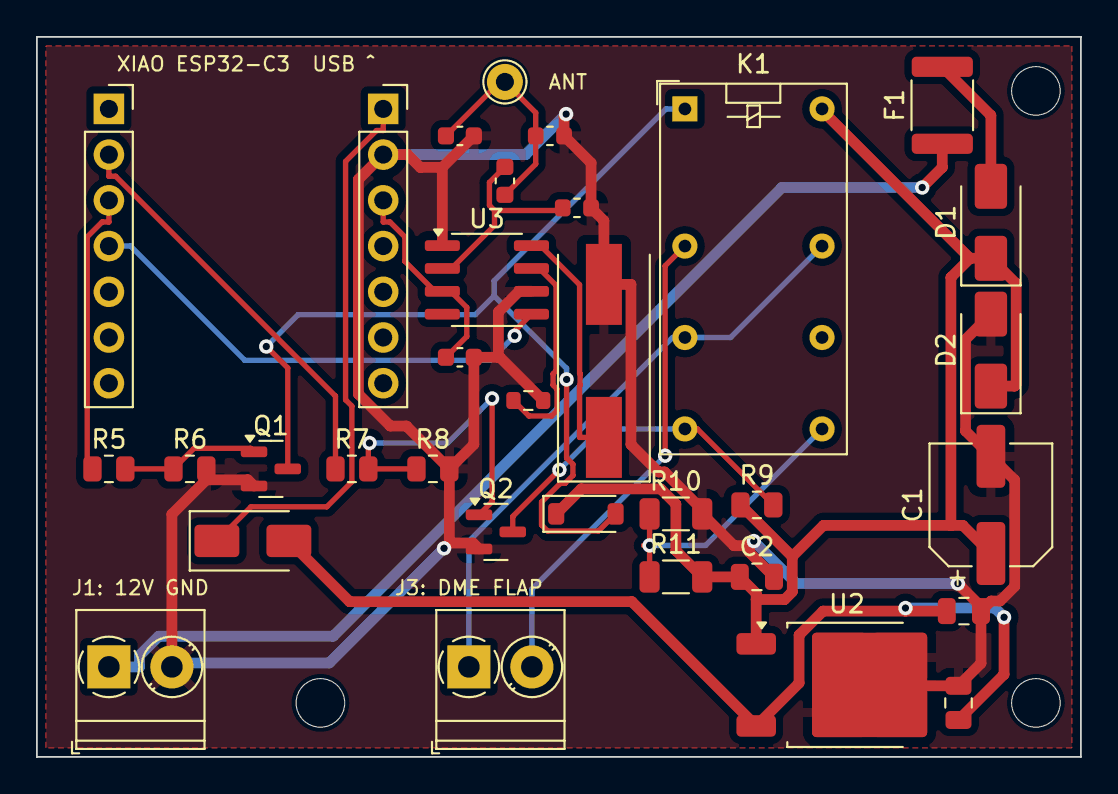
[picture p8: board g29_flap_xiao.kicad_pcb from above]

Board: 2 copper layers, 58.0 x 40.0 mm, 36 parts (0 on the bottom side), 21 nets.

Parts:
ANT1: ANT 17cm; TestPoint_THTPad_D2.0mm_Drill1.0mm
C1: 100u 35V; CP_Elec_6.3x7.7
C2, C3: 100n; C_0805_2012Metric
C4: 10u; C_0805_2012Metric
C7: 1.8p C0G; C_0603_1608Metric
C8: 6.8p C0G; C_0603_1608Metric
C9: 1u; C_0603_1608Metric
D1, D6: SS14; D_SMA
D2: SMAJ20A; D_SMA
D5: 1N4148W; D_SOD-123
F1: PTC 0.5A; Fuse_1812_4532Metric
H1, H2, H3: M2.5
J1: PWR; TerminalBlock_Phoenix_PT-1,5-2-3.5-H_1x02_P3.50mm_Horizontal
J3: FLAP; TerminalBlock_Phoenix_PT-1,5-2-3.5-H_1x02_P3.50mm_Horizontal
K1: G5V-2-H1 DC12; Relay_DPDT_Omron_G5V-2
L1: 27nH; L_0603_1608Metric
L2: 47nH; L_0603_1608Metric
Q1, Q2: S8050; SOT-23
R5, R7: 1k; R_0805_2012Metric
R6, R8: 100k; R_0805_2012Metric
R9: 1k opt; R_0805_2012Metric
R10: DUM-GND; R_1206_3216Metric
R11: DUM-12V; R_1206_3216Metric
R12: 0R; R_0603_1608Metric
U1A: XIAO left; PinSocket_1x07_P2.54mm_Vertical
U1B: XIAO right; PinSocket_1x07_P2.54mm_Vertical
U2: 78M05; TO-252-2
U3: SYN480R; SOIC-8_3.9x4.9mm_P1.27mm
Y1: 13.52127MHz; Crystal_SMD_HC49-SD

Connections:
+3V3: C9.1, U1B.3, U3.3
+5V: C3.1, C4.1, D6.2, U2.3
+5V_X: D6.1, U1B.1
+12V: C1.1, C2.1, D1.1, D2.1, D5.1, K1.16, R9.1, R11.2, U2.1
+12V_F: D1.2, F1.2
+12V_IN: F1.1, J1.1
ACT_SIG: J3.2, K1.4
ANT_IN: ANT1.1, C7.1, C8.1, L1.1
COIL_N: D5.2, K1.1, Q1.3
DME_SIG: J3.1, K1.6, K1.13
DUMMY: K1.9, R10.1, R11.1
GND: C1.2, C2.2, C3.2, C4.2, C7.2, C9.2, D2.2, J1.2, L1.2, L2.2, Q1.2, Q2.2, R6.2, R8.2, R10.2, R12.2, U1B.2, U2.2, U3.1, U3.6, Y1.2
IO3: R7.1, U1A.2
IO4: R5.1, U1A.3
IO5: U1A.4, U3.5
PWM_OUT: K1.8, Q2.3, R9.2
Q1_B: Q1.1, R5.2, R6.1
Q2_B: Q2.1, R7.2, R8.1
RF_IN: C8.2, L2.1, U3.2
SQ: R12.1, U3.7
XTAL: U3.8, Y1.1

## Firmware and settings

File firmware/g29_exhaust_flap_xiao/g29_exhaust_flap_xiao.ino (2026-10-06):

/*
  BMW Z4 G29 M40i - Exhaust flap override controller (ESP32)

  Modes:
    AUTO          relay released -> the car (DME) drives the actuator (factory behaviour)
    FORCED_OPEN   relay energized -> ESP32 sends the "open" PWM
    FORCED_CLOSED relay energized -> ESP32 sends the "closed" PWM (auto-reverts after a timeout)

  Fail-safe: at power-up, on reset, or if the ESP32 dies, the relay is released
  and the car is back in control. R6/R8 (100k) on the PCB keep both transistors off during boot.

  Controls: the original 433 MHz key fob, and the dashboard button of the commercial kit.
  The button is not wired to this board: its cabin box transmits on 433 MHz like the fob,
  so both arrive through the on-board SYN480R receiver (U3, DO -> GPIO5). Capture the codes
  of both with the Serial Monitor.

  Libraries: rc-switch (sui77) - install from the Arduino Library Manager.
  Board: XIAO_ESP32C3 (Arduino core 2.x or 3.x). Enable "USB CDC On Boot" for Serial Monitor.

  !!! The PWM values below are PLACEHOLDERS. Measure the real DME signal first. !!!
*/

#include <WiFi.h>
#include <RCSwitch.h>

// ===================== Pins (Seeed XIAO ESP32-C3, strapping pins 2/8/9 avoided) =====================
constexpr int PIN_PWM      = 3;   // D1 -> PWM driver transistor
constexpr int PIN_RELAY    = 4;   // D2 -> relay driver transistor. HIGH = ESP32 controls the actuator
constexpr int PIN_RF_RX    = 5;   // D3 <- SYN480R DO (on-board 433 MHz receiver)
constexpr int PIN_LED      = -1;  // XIAO ESP32-C3 has no user LED

// ===================== Signal parameters - SET FROM YOUR MEASUREMENTS =====================
constexpr uint32_t PWM_FREQ_HZ     = 100;    // PLACEHOLDER - copy the measured DME frequency
constexpr uint8_t  PWM_RES_BITS    = 10;
constexpr float    DUTY_OPEN_PCT   = 95.0f;  // F30 data, verify on the G29
constexpr float    DUTY_CLOSED_PCT = 5.0f;   // F30 data, verify on the G29
constexpr bool     PWM_INVERTED    = true;   // true with a low-side MOSFET + pull-up to 12V

// ===================== Behaviour =====================
constexpr bool     BTN_OFF_MEANS_AUTO       = true;  // dashboard-button OFF returns to factory mode
constexpr bool     ALLOW_FORCED_CLOSED      = true;  // remote OFF forces the flap closed
constexpr uint32_t FORCED_CLOSED_TIMEOUT_MS = 15UL * 60UL * 1000UL;  // back to AUTO after 15 min
constexpr uint32_t RELAY_SETTLE_MS          = 20;

// ===================== Remote codes =====================
// Leave at 0, open the Serial Monitor (115200), press each fob button, then paste the codes here.
constexpr unsigned long RF_CODE_ON   = 0;   // fob ON
constexpr unsigned long RF_CODE_AUTO = 0;   // fob AUTO
constexpr unsigned long RF_CODE_OFF  = 0;   // fob OFF
// Dashboard button (via the kit's cabin box). May be the same codes as the fob; if so leave at 0.
constexpr unsigned long RF_CODE_BTN_ON  = 0;
constexpr unsigned long RF_CODE_BTN_OFF = 0;
constexpr uint32_t      RF_REPEAT_IGNORE_MS = 600;  // fobs repeat the code while held

// ===================== State =====================
enum class Mode { AUTO, FORCED_OPEN, FORCED_CLOSED };
Mode     mode      = Mode::AUTO;
uint32_t modeSince = 0;
RCSwitch rf;

// ===================== PWM helpers (core 2.x and 3.x) =====================
void pwmInit() {
#if ESP_ARDUINO_VERSION_MAJOR >= 3
  ledcAttach(PIN_PWM, PWM_FREQ_HZ, PWM_RES_BITS);
#else
  ledcSetup(0, PWM_FREQ_HZ, PWM_RES_BITS);
  ledcAttachPin(PIN_PWM, 0);
#endif
}

void pwmWriteRaw(uint32_t duty) {
#if ESP_ARDUINO_VERSION_MAJOR >= 3
  ledcWrite(PIN_PWM, duty);
#else
  ledcWrite(0, duty);
#endif
}

uint32_t dutyFromWirePct(float wirePct) {
  float pct = PWM_INVERTED ? (100.0f - wirePct) : wirePct;
  const uint32_t maxDuty = (1UL << PWM_RES_BITS) - 1;
  return (uint32_t)(pct / 100.0f * maxDuty + 0.5f);
}

// ===================== Mode handling =====================
const char* modeName(Mode m) {
  switch (m) {
    case Mode::AUTO:          return "AUTO (car in control)";
    case Mode::FORCED_OPEN:   return "FORCED OPEN";
    case Mode::FORCED_CLOSED: return "FORCED CLOSED";
  }
  return "?";
}

void applyMode(Mode m) {
  if (m == Mode::FORCED_CLOSED && !ALLOW_FORCED_CLOSED) m = Mode::AUTO;
  if (m == mode) return;

  if (m == Mode::AUTO) {
    digitalWrite(PIN_RELAY, LOW);   // hand control back to the car first
    delay(RELAY_SETTLE_MS);
    pwmWriteRaw(0);                 // driver MOSFET off
  } else {
    float pct = (m == Mode::FORCED_OPEN) ? DUTY_OPEN_PCT : DUTY_CLOSED_PCT;
    pwmWriteRaw(dutyFromWirePct(pct));  // signal ready before switching
    if (mode == Mode::AUTO) {
      delay(RELAY_SETTLE_MS);
      digitalWrite(PIN_RELAY, HIGH);
    }
  }

  mode = m;
  modeSince = millis();
  if (PIN_LED >= 0) digitalWrite(PIN_LED, mode == Mode::AUTO ? LOW : HIGH);
  Serial.printf("[mode] %s\n", modeName(mode));
}

// ===================== Inputs =====================
void handleRemote() {
  static unsigned long lastCode = 0;
  static uint32_t lastCodeAt = 0;

  if (!rf.available()) return;
  unsigned long code = rf.getReceivedValue();
  unsigned int bits = rf.getReceivedBitlength();
  unsigned int proto = rf.getReceivedProtocol();
  rf.resetAvailable();

  if (code == 0) return;
  uint32_t now = millis();
  if (code == lastCode && now - lastCodeAt < RF_REPEAT_IGNORE_MS) {
    lastCodeAt = now;
    return;
  }
  lastCode = code;
  lastCodeAt = now;

  Serial.printf("[rf] code=%lu bits=%u protocol=%u\n", code, bits, proto);

  if (RF_CODE_ON   != 0 && code == RF_CODE_ON)   applyMode(Mode::FORCED_OPEN);
  else if (RF_CODE_AUTO != 0 && code == RF_CODE_AUTO) applyMode(Mode::AUTO);
  else if (RF_CODE_OFF  != 0 && code == RF_CODE_OFF)  applyMode(Mode::FORCED_CLOSED);
  else if (RF_CODE_BTN_ON  != 0 && code == RF_CODE_BTN_ON)  applyMode(Mode::FORCED_OPEN);
  else if (RF_CODE_BTN_OFF != 0 && code == RF_CODE_BTN_OFF)
    applyMode(BTN_OFF_MEANS_AUTO ? Mode::AUTO : Mode::FORCED_CLOSED);
}

void handleTimeouts() {
  if (mode == Mode::FORCED_CLOSED && millis() - modeSince >= FORCED_CLOSED_TIMEOUT_MS) {
    Serial.println("[safety] forced-closed timeout, back to AUTO");
    applyMode(Mode::AUTO);
  }
}

// ===================== Setup / loop =====================
void setup() {
  pinMode(PIN_RELAY, OUTPUT);
  digitalWrite(PIN_RELAY, LOW);  // car in control, before anything else
  if (PIN_LED >= 0) { pinMode(PIN_LED, OUTPUT); digitalWrite(PIN_LED, LOW); }

  pwmInit();
  pwmWriteRaw(0);

  WiFi.mode(WIFI_OFF);           // not used for now
  Serial.begin(115200);

  rf.enableReceive(digitalPinToInterrupt(PIN_RF_RX));

  Serial.println();
  Serial.println("G29 exhaust flap controller - started in AUTO (car in control)");
  if (RF_CODE_ON == 0 || RF_CODE_AUTO == 0 || RF_CODE_OFF == 0) {
    Serial.println("Remote codes not set: press each fob button, then the dashboard button, and copy the codes shown.");
  }
  Serial.printf("PWM %lu Hz, open %.0f%%, closed %.0f%% (verify these on the car!)\n",
                (unsigned long)PWM_FREQ_HZ, DUTY_OPEN_PCT, DUTY_CLOSED_PCT);
}

void loop() {
  handleRemote();
  handleTimeouts();
}

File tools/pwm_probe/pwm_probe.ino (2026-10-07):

/*
  PWM probe for the G29 flap project - Seeed XIAO ESP32-C3

  Measures frequency, duty cycle and high/low times of a 12 V logic signal.
  Wiring: signal -> 10k -> GPIO5 (D3), 3.3k from GPIO5 to GND, grounds common.
  (12 V * 3.3 / 13.3 = 3.0 V at the pin; never feed 12 V directly.)

  Serial Monitor 115200. Prints once per second. "DC high"/"DC low" when no edges
  are seen, which is how you tell a true DC level from a PWM.
*/
constexpr int PIN_IN = 5;

volatile uint32_t tRise = 0, tFall = 0;
volatile uint32_t highSum = 0, lowSum = 0, periodSum = 0;
volatile uint32_t edges = 0, periods = 0;
volatile uint32_t minHigh = UINT32_MAX, maxHigh = 0;

void IRAM_ATTR onEdge() {
  uint32_t now = micros();
  if (digitalRead(PIN_IN)) {                 // rising edge
    if (tRise) { periodSum += now - tRise; periods++; }
    if (tFall) lowSum += now - tFall;
    tRise = now;
  } else {                                   // falling edge
    if (tRise) {
      uint32_t h = now - tRise; highSum += h;
      if (h < minHigh) minHigh = h;
      if (h > maxHigh) maxHigh = h;
    }
    tFall = now;
  }
  edges++;
}

void setup() {
  Serial.begin(115200);
  pinMode(PIN_IN, INPUT);
  attachInterrupt(digitalPinToInterrupt(PIN_IN), onEdge, CHANGE);
  delay(1500);
  Serial.println("\nPWM probe on GPIO5: freq / duty / high / low, 1 s windows");
}

void loop() {
  delay(1000);
  noInterrupts();
  uint32_t e = edges, p = periods, hs = highSum, ls = lowSum, ps = periodSum;
  uint32_t mnH = minHigh, mxH = maxHigh;
  edges = periods = highSum = lowSum = periodSum = 0; minHigh = UINT32_MAX; maxHigh = 0;
  interrupts();

  if (p < 2) {
    Serial.printf("no PWM: DC %s (%u edges)\n", digitalRead(PIN_IN) ? "HIGH" : "LOW", e);
    return;
  }
  float period = (float)ps / p;                 // us
  float high = (float)hs / p, low = (float)ls / p;
  Serial.printf("f = %7.1f Hz   duty(high) = %5.1f %%   high = %7.1f us   low = %7.1f us   jitter(high) %u..%u us\n",
                1e6f / period, 100.0f * high / (high + low), high, low, mnH, mxH);
}

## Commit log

2026-10-05 Add harness survey; clarify board power source; drop v1 references
    - docs/harness.md: where the actuator wiring enters the body (floor grommet
    under the rear power distribution box), wire identification with a tone
    generator and multimeter, why the ground pin does not tone, cautions in
    the loom.
    - installation.md: J1 power comes from a fused trunk source and chassis
    ground, not from the actuator wires; only the signal wire is cut.
    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
2026-10-05 Remove v1 DevKitC board: BOM
    [bom.csv]
2026-10-05 Remove v1 DevKitC board: KiCad PCB
    [g29_flap_controller.kicad_pcb]
2026-10-05 Remove v1 DevKitC board: Gerbers
2026-10-05 Remove v1 DevKitC board: back preview
2026-10-05 Remove v1 DevKitC board: front preview
2026-10-05 Add JLCPCB assembly files for the XIAO board
    - jlcpcb/bom.csv + positions.csv: Standard (THT) assembly set for the current
    board. Mid X/Y computed from pad centres (KiCad THT footprint origins sit on
    pad 1). 30 parts placed by JLC; PTC, XIAO and RXB6 hand-soldered.
    - jlcpcb/HOW_TO_UPLOAD.md: order settings, parts-matching notes with which
    LCSC numbers were verified, polarity checks for the preview.
    - jlcpcb/smt-respin-*.{csv,md}: optional SMT variant for a smaller board.
    [bom.csv, positions.csv, smt-respin-bom.csv]
2026-10-05 jlcpcb: positions back to KiCad footprint origins
    Pad-centroid coordinates fought JLCPCB's own per-part offsets and
    misplaced most parts in the preview. Footprint origins (pad 1) are
    what a KiCad export produces and what JLC's library expects. Notes
    updated to say so and to explain the cosmetic overhang on axial parts.
    [positions.csv]
2026-10-05 jlcpcb/positions.csv: K1 at body centre, rotated 90
    JLC's G5V-2 model is centre-origin with the long axis along X; the
    KiCad footprint is pin-1 origin with pin rows along Y. All other parts
    keep KiCad footprint origins.
    [positions.csv]
2026-10-05 jlcpcb/positions.csv: K1 rotation 270 (pin 1 at top)
    At 90 the JLC preview showed pin 1 at the bottom, i.e. the relay
    180 degrees off. On a DPDT that swaps NC and NO between poles and
    would break the fail-safe path.
    [positions.csv]
2026-10-06 Board v3 with on-board SYN480R receiver: docs and JLCPCB files
    - README: v3 (58 x 40 mm, SYN480R + crystal, no RXB6), status, history tags.
    - installation, shopping list: antenna pad instead of module, J1 + J3 only.
    - jlcpcb/bom.csv: 22 lines, every one with the LCSC number matched in Oct 2026.
    - jlcpcb/positions.csv: 29 placed parts. HOW_TO_UPLOAD rewritten.
    Binary artefacts (KiCad board, Gerber zip, previews, STLs) follow by direct
    upload; see hardware/v3-xiao-esp32c3/README once added.
    [bom.csv, positions.csv]
2026-10-06 Firmware and generator for board v3 (on-board SYN480R receiver)
    - firmware: RXB6 references replaced by the on-board receiver; dashboard GPIO
    inputs removed; RF_CODE_BTN_ON/OFF for the kit's cabin box.
    - tools/pcb-generator: v3 netlist with the SYN480R section (datasheet matching
    network, crystal), 58 x 40 mm, M2.5 holes, edge keep-out ring; finishing script
    with ground pours, silkscreen and DRC.
    [g29_exhaust_flap_xiao.ino]
2026-10-06 Enclosure for board v3: OpenSCAD model, assembly view, README
    STLs and renders are binary and follow by direct upload.
    [assembly.scad, enclosure.scad]
2026-10-06 Remove v2 board (1/10): bom.csv
    [bom.csv]
2026-10-06 Remove v2 board (2/10): KiCad PCB
    [g29_flap_xiao.kicad_pcb]
2026-10-06 Remove v2 board (3/10): Gerbers
2026-10-06 Remove v2 board (4/10): jlcpcb/HOW_TO_UPLOAD.md
2026-10-06 Remove v2 board (5/10): jlcpcb/bom.csv
    [bom.csv]
2026-10-06 Remove v2 board (6/10): jlcpcb/positions.csv
    [positions.csv]
2026-10-06 Remove v2 board (7/10): jlcpcb/smt-respin-bom.csv
    [smt-respin-bom.csv]
2026-10-06 Remove v2 board (8/10): jlcpcb/smt-respin-notes.md
2026-10-06 Remove v2 board (9/10): preview_back.png
2026-10-06 Remove v2 board (10/10): preview_front.png
2026-10-07 tools/pwm_probe: XIAO sketch to measure frequency and duty of the flap signal
    Divider 10k/3.3k into GPIO5. Prints f, duty, high/low times once per
    second; reports "DC HIGH/LOW" when there are no edges.
2026-10-07 findings: internet evidence on the DME signal (100 Hz, levels, polarity unsettled, actuator reply)
2026-10-12 firmware: fob codes measured (address 0xE91C), address filter + button nibble decode
    ON 954817 / OFF 954818 / AUTO 954820, 24-bit EV1527-style (20-bit address,
    4-bit button). Codes from the fob's address are decoded by button nibble;
    a second address slot is reserved for the kit's cabin box.
2026-10-12 firmware: optional ON toggle (ON_TOGGLES_TO_AUTO) for a single-code dashboard button
    Off by default. With a 2 s guard so a held fob button does not toggle back.
